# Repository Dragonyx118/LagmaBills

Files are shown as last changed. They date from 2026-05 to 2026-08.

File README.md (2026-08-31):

# L.A.G.M.A. B.I.L.L.S.
**L**and **A**nd **G**round-to-**M**idair **A**gent — **B**uilt for **I**ntelligent **L**inked **L**ocal **S**upport










A Mecanum-wheeled robot for civil protection, powered by a Raspberry Pi orchestrating two custom ESP32 PCBs, sensors, a robotic arm, and a drone companion over MQTT. It navigates autonomously, maps its environment, avoids obstacles, and is controlled via voice AI, a MAUI app, or browser dashboard.

Presentato ad Arduino Day 2025.

## Team
- **Daniele Cerioli (Dragonyx)** — firmware, software, PCB, integrazione di sistema
- **Simone Panelli (Tabella_Brodosa)** — componenti AI
- **Andrei Corduneanu** — modellazione 3D, falegnameria

## Repositories

| Repo | Contenuto |
|---|---|
| `lagmabills` (questo) | Firmware ESP32, codice Python Raspberry Pi, PCB (KiCad), modelli 3D |
| [`lagmabills-app`](https://github.com/Dragonyx118/LagmaIpp) | App companion LagmaIpp (.NET MAUI, Windows + Android) |
| [`lagmabills-web`](https://github.com/Dragonyx118/LagmaBills-Web) | Sito web del progetto |

## Struttura del repository

```
lagmabills/
├── firmware/
│   ├── firm_esp32_motori/     # Firmware PCBmotori (PlatformIO)
│   └── firm_esp32_sensori/    # Firmware PCBsensori (PlatformIO)
├── raspberry/
│   ├── odometria.py           # Odometria encoder Mecanum
│   ├── occupancyGrid.py       # Mappatura locale log-odds
│   ├── navigator.py           # Navigazione autonoma Potential Field
│   ├── GPS.py                 # Lettura NEO-6M → MQTT
│   ├── myViewerServer.py      # Dashboard web (HTTP + WebSocket + Leaflet)
│   ├── rasp_cam/              # Streaming camera OV5647
│   ├── odo_module/            # Moduli navigazione/mappatura aggiuntivi
│   └── Bamberg/
│       ├── ESP-IDF/           # Firmware ESP-Drone (ESP-IDF)
│       └── firm_drone/        # Bridge MQTT ↔ CRTP/UDP drone + test
├── AI_Bepo/                   # Server AI vocale (wakeword, STT, LLM, TTS)
├── AmazingArm/                # Modelli e risorse braccio robotico
├── PCB/
│   ├── PCBmotori/             # KiCad — ESP32 motori (4-layer)
│   ├── PCBsensori/            # KiCad — ESP32 sensori
│   └── PCBalim/               # KiCad — distribuzione alimentazione
├── Hardware/                  # Datasheet, pinout, power budget, BOM
├── models_3d/                 # Modelli 3D stampabili
└── docs/
    ├── img/                   # Foto e video dimostrativi
    └── LAGMABILLS.pptx        # Presentazione progetto
```

## Hardware

| Componente | Descrizione |
|---|---|
| Raspberry Pi 4B (4GB) | Cervello centrale, broker MQTT, Tailscale VPN |
| PCBmotori (ESP32, 4-layer) | 4× JGA25-370 Mecanum + encoder, 2× TB6612FNG, I2C slave 0x08 |
| PCBsensori (ESP32) | 6× HC-SR04, MPU-6050, 3× TCRT5000, PCA9685 → braccio 6DOF, I2C slave 0x09 |
| PCBalim | Distribuzione alimentazione custom, 2× LiPo 3S 5500mAh |
| ESP-Drone (ESP32-S2) | Ricognizione aerea, CRTP/UDP |
| OV5647 CSI | Camera RPi, stream MJPEG |
| ReSpeaker 2-Mic HAT | WM8960, wakeword ONNX, DOA GCC-PHAT |
| NEO-6M GPS | Tracciamento posizione world frame |
| Display 7" HDMI | Faccia animata responsiva (RPi) |
| Speaker Bluetooth | Audio stereo, musica / sirene / TTS |

Dettagli completi in [`Hardware/BOM.xlsx`](Hardware/BOM.xlsx) e [`Hardware/pinoutEsp32.xlsx`](Hardware/pinoutEsp32.xlsx).

## Architettura software

Tutto comunica via MQTT (Mosquitto su RPi, `localhost:1883`, accessibile anche via Tailscale).

```
              ┌─────────────────────────┐
              │  Mosquitto Broker (RPi) │
              └────────────┬────────────┘
     ┌──────────┬──────────┼──────────┬──────────┐
     │          │          │          │          │
odometria   occupancy   navigator  drone_bridge  GPS
     │        grid.py      .py        .py       .py
     │          │
  robot/     robot/
 motori/     mappa/
 stato       grid
```

| Topic | Direzione | Descrizione |
|---|---|---|
| `robot/motori/cmd` | Pi → ESP32 | Comandi movimento |
| `robot/motori/stato` | ESP32 → Pi | Encoder + PWM |
| `robot/sensori/distanze` | ESP32 → Pi | Distanze HC-SR04 (cm) |
| `robot/sensori/imu` | ESP32 → Pi | Accelerometro + giroscopio |
| `robot/odometria` | Pi → tutti | Posa X, Y, θ |
| `robot/mappa/grid` | Pi → viewer | Occupancy grid JSON |
| `robot/cliff/stato` | Pi → tutti | Stato sensori cliff |
| `robot/nav/cmd` | app → Pi | start / stop / reset_goal |
| `robot/nav/goal` | app → Pi | Goal `{x, y}` in world frame |
| `drone/cmd/rpyt` | app → Pi | Roll, pitch, yaw, thrust |

## Installazione (Raspberry Pi)

```bash
# Dipendenze Python
pip install paho-mqtt numpy sounddevice onnxruntime websockets \
            flask flask-socketio pyserial pynmea2 faster-whisper psutil

# Mosquitto broker
sudo apt install mosquitto mosquitto-clients
sudo systemctl enable mosquitto

# Driver ReSpeaker 2-Mic HAT
# Seguire istruzioni in Hardware/ o repo seeed-voicecard

# Avviare i moduli (esempio)
python3 raspberry/odometria.py &
python3 raspberry/occupancyGrid.py &
python3 raspberry/navigator.py &
python3 raspberry/GPS.py &
python3 raspberry/myViewerServer.py &
```

Dashboard web: `http://<ip-pi>:8080`

## Firmware ESP32 (PlatformIO)

Le cartelle in `firmware/` sono progetti PlatformIO completi e pronti da compilare (`pio run`).

Librerie richieste (`platformio.ini`):
- PubSubClient
- ArduinoJson
- MPU6050_light
- Adafruit PWM Servo Driver
- Preferences

Le credenziali WiFi e broker MQTT vengono salvate in NVS e possono essere aggiornate via I2C dal Pi senza reflashare.

📦 **Non vuoi compilare tu stesso?** Scarica le cartelle sorgente aggiornate automaticamente ad ogni modifica dalla sezione [Releases](../../releases).

## Pipeline AI vocale

```
ReSpeaker mic → wakeword ("hey nova") → DOA GCC-PHAT (stima direzione)
    → WebSocket stream PCM16 raw
    → Whisper STT → LLM (Ollama) → Piper TTS (voce "Miro" italiano)
    → audio risposta → Speaker Bluetooth
```

## Demo

**Primi test di movimento**

https://github.com/Dragonyx118/LagmaBills/raw/main/docs/img/first_test_move.mp4

**Prototipo in movimento**

https://github.com/Dragonyx118/LagmaBills/raw/main/docs/img/proto_move.mp4

**Test braccio robotico**

https://github.com/Dragonyx118/LagmaBills/raw/main/docs/img/test_arm.mp4

**Struttura in legno**

https://github.com/Dragonyx118/LagmaBills/raw/main/docs/img/wood_body.mp4

> GitHub riproduce automaticamente i link diretti `.mp4` di un repository quando incollati su una riga propria nel README, mostrando un player inline.

## Licenza

[Hippocratic License 3.0](LICENSE) (HL3-CL-ECO-LAW-MIL-SV) — © 2025 Dragonyx

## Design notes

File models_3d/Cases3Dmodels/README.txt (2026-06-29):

Raspberry Pi Cam Mount by ChisTompso on Thingiverse: https://www.thingiverse.com/thing:3445264

Summary:
I designed this thing for mounting my PiCam to my garage ceiling, but you could really use it for a variety of surfaces, hanging or standing.  Vertical vs. Horiztonal orientation of the PiCam video can be changed with a few quick settings.  It was specifically designed for the "Kuman for Raspberry PI Camera Module 5MP 1080p OV5647 Sensor HD Video Webcam Supports Night Vision SC15 (Raspberry PI Camera Module)", which can be found on Amazon and other places.Assembly of the mount requires a mixture of M3 screw/nut hardware.  You can find mixed assortments of M3 hardware easily on Amazon.  ABOUT THE MOUNTING BASE:Mounting Screws:  Two are required.  The base of the mount has a 3.5 mm radius counterbore for the screw heads, and a 2mm radius hole for the screws.  I just used some random dry wall screws that I had around the house.There are two mounting bases!  One lets the cable exit in the direction that the camera is looking (front cable exit). The other lets the cable exit in the opposite direction from where the camera is looking (rear cable exit).

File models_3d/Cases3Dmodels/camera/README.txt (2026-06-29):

Raspberry Pi3 IR Camera Wide-angle waterproof housing by bujna94 on Thingiverse: https://www.thingiverse.com/thing:3542321

Summary:
Hi, I designed this housing for: MakerHawk Raspberry Pi3 Camera IR Fisheye Wide-angle 175 Degree 5MP OV5647. Link to Amazon - https://amzn.to/2G10jXEI was printing it with PETG 100% infill, but PLA or ABS will be fine too. (PLA is not recommended for outdoor use). Gaskets I print with TPU 100% infill again. My printer is Ender 3 &amp; layer height was 0.3mm.The reason why the camera lens is not covered with plexiglass is night vision. If I just cover the whole camera with plexiglass, IR lights will reflect and you will be not able to see almost anything.I used 4 M3x16mm stainless steel pan head screws.It's not probably waterproof enough if you try to swim with it (didn't try), but more than enough for rain.You can also use some silicone to seal cable.Acrylic sheet is thick 3mm.Enjoy

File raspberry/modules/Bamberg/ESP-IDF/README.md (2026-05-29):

# L.A.G.M.A. B.I.L.L.S.
### *Land And Ground-to-Midair Agent — Built for Intelligent Linked Local Support*

> A Mecanum-wheeled robot for civil protection, powered by a Raspberry Pi orchestrating two custom ESP32 PCBs, sensors, a robotic arm, and a drone companion over MQTT. It navigates autonomously, maps its environment, avoids obstacles, and is controlled via voice AI, a MAUI app, or browser dashboard.

---

## Repositories

| Repo | Contenuto |
|---|---|
| **lagmabills** *(questo)* | Firmware ESP32, codice Python Raspberry Pi, PCB (KiCad) |
| **lagmabills-app** | App companion LagmaIpp (.NET MAUI, Windows + Android) |

---

## Struttura del repository

```
lagmabills/
├── firmware/
│   ├── esp32_motori/          # Firmware PCBmotori (PlatformIO)
│   └── esp32_sensori/         # Firmware PCBsensori (PlatformIO)
├── raspberry/
│   ├── wakeword.py            # Wakeword detection + DOA + WebSocket stream
│   ├── odometria.py           # Odometria encoder Mecanum
│   ├── occupancyGrid.py       # Mappatura locale log-odds
│   ├── navigator.py           # Navigazione autonoma Potential Field
│   ├── GPS.py                 # Lettura NEO-6M → MQTT
│   ├── drone_mqtt_bridge.py   # Bridge MQTT → CRTP/UDP drone
│   ├── myViewerServer.py      # Dashboard web (HTTP + WebSocket + Leaflet)
│   └── streamCamera.py        # Stream MJPEG OV5647
├── pcb/
│   ├── PCBmotori/             # KiCad — ESP32 motori (4-layer)
│   ├── PCBsensori/            # KiCad — ESP32 sensori
│   └── PCBalim/               # KiCad — distribuzione alimentazione
└── docs/
    └── LAGMABILLS.pptx        # Presentazione progetto
```

---

## Hardware

| Componente | Descrizione |
|---|---|
| Raspberry Pi 4B (4GB) | Cervello centrale, broker MQTT, Tailscale VPN |
| PCBmotori (ESP32, 4-layer) | 4× JGA25-370 Mecanum + encoder, 2× TB6612FNG, I2C slave `0x08` |
| PCBsensori (ESP32) | 6× HC-SR04, MPU-6050, 3× TCRT5000, PCA9685 → braccio 6DOF, I2C slave `0x09` |
| PCBalim | Distribuzione alimentazione custom, 2× LiPo 3S 5500mAh |
| ESP-Drone (ESP32-S2) | Ricognizione aerea, CRTP/UDP `192.168.43.42:2390` |
| OV5647 CSI | Camera RPi, stream MJPEG su porta `8080` |
| ReSpeaker 2-Mic HAT | WM8960, wakeword ONNX, DOA GCC-PHAT |
| NEO-6M GPS | Tracciamento posizione world frame |
| Display 7" HDMI | Faccia animata responsiva (RPi) |
| Speaker Bluetooth | Audio stereo, musica / sirene / TTS |

---

## Architettura software

Tutto comunica via **MQTT** (Mosquitto su RPi, `localhost:1883`, accessibile anche via Tailscale).

```
                    ┌─────────────────────────┐
                    │   Mosquitto Broker (RPi) │
                    └────────────┬────────────┘
           ┌──────────┬──────────┼──────────┬──────────┐
           │          │          │          │          │
      odometria   occupancy   navigator  drone_bridge  GPS
           │        grid.py      .py        .py       .py
           │          │
        robot/     robot/
       motori/     mappa/
       stato       grid
```

**Topic principali:**

| Topic | Direzione | Descrizione |
|---|---|---|
| `robot/motori/cmd` | Pi → ESP32 | Comandi movimento |
| `robot/motori/stato` | ESP32 → Pi | Encoder + PWM |
| `robot/sensori/distanze` | ESP32 → Pi | Distanze HC-SR04 (cm) |
| `robot/sensori/imu` | ESP32 → Pi | Accelerometro + giroscopio |
| `robot/odometria` | Pi → tutti | Posa X, Y, θ |
| `robot/mappa/grid` | Pi → viewer | Occupancy grid JSON |
| `robot/cliff/stato` | Pi → tutti | Stato sensori cliff |
| `robot/nav/cmd` | app → Pi | `start` / `stop` / `reset_goal` |
| `robot/nav/goal` | app → Pi | Goal `{x, y}` in world frame |
| `drone/cmd/rpyt` | app → Pi | Roll, pitch, yaw, thrust |
| `macchinina/audio/stop` | server → Pi | Stop streaming audio |

---

## Installazione (Raspberry Pi)

```bash
# Dipendenze Python
pip install paho-mqtt numpy sounddevice onnxruntime websockets \
            flask flask-socketio pyserial pynmea2 faster-whisper psutil

# Mosquitto broker
sudo apt install mosquitto mosquitto-clients
sudo systemctl enable mosquitto

# Driver ReSpeaker 2-Mic HAT
# Seguire istruzioni in docs/ o repo seeed-voicecard

# Avviare i moduli (esempio)
python3 raspberry/odometria.py &
python3 raspberry/occupancyGrid.py &
python3 raspberry/navigator.py &
python3 raspberry/GPS.py &
python3 raspberry/myViewerServer.py &
python3 raspberry/streamCamera.py &
```

**Dashboard web:** `http://<ip-pi>:8080`
**Stream camera:** `http://<ip-pi>:8080/stream`
**Accesso remoto:** `http://100.100.61.49:8080` (via Tailscale)

---

## Firmware ESP32 (PlatformIO)

Librerie richieste (`platformio.ini`):
```
PubSubClient
ArduinoJson
MPU6050_light
Adafruit PWM Servo Driver
Preferences
```

Le credenziali WiFi e broker MQTT vengono salvate in NVS e possono essere aggiornate via I2C dal Pi senza reflashare.

---

## Pipeline AI vocale

```
ReSpeaker mic → wakeword.py (hey_no_va.onnx)
    → DOA GCC-PHAT (stima direzione)
    → WebSocket stream PCM16 raw → ws://100.120.32.86:5000
    → Whisper STT → LLM → Piper TTS (voce "Miro" italiano)
    → audio risposta → Speaker Bluetooth
```

---

## Licenza

MIT License — © 2025 Daniele Cerioli

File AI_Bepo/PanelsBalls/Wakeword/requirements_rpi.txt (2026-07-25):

# requirements_rpi.txt - Solo per inferenza su Raspberry Pi
# Installa con: pip install -r requirements_rpi.txt
#
# NOTA: Su RPi 4/5 con Raspberry Pi OS Bookworm (64-bit)
#   sudo apt-get install -y portaudio19-dev libatlas-base-dev

# Inferenza (scegli UNO tra TFLite o ONNX)
tflite-runtime>=2.14.0       # OPZIONE A: più leggero (consigliato RPi)
# onnxruntime>=1.16.3        # OPZIONE B: onnx (migliore compatibilità)

# Audio streaming
pyaudio>=0.2.13
numpy>=1.24.0

# openWakeWord runtime (senza TF completo)
openwakeword>=0.6.0

# VAD leggero
webrtcvad>=2.0.10            # Google WebRTC VAD - <1ms latenza

# Utilities
pyyaml>=6.0.1

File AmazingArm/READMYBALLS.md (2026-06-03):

# 🤖 Robot Arm - Guida Completa

## Architettura del sistema

```
┌─────────────────────────────────────────────────────────┐
│  Smartphone / PC (Browser)                              │
│  └── Web Dashboard (index.html)                         │
└─────────────────────┬───────────────────────────────────┘
                      │ HTTP REST (WiFi)
┌─────────────────────▼───────────────────────────────────┐
│  Raspberry Pi                                           │
│  └── robot_arm_server.py (Flask, porta 5000)            │
└─────────────────────┬───────────────────────────────────┘
                      │ I2C (GPIO 2/3, bus 1)
┌─────────────────────▼───────────────────────────────────┐
│  ESP32                                                  │
│  ├── I2C slave (GPIO 16/17) ← RPi                       │
│  └── I2C master (GPIO 21/22) → PCA9685                  │
└─────────────────────┬───────────────────────────────────┘
                      │ PWM (16 canali)
┌─────────────────────▼───────────────────────────────────┐
│  PCA9685 Servo Driver                                   │
│  ├── CH0 → Servo 0: Base    (MG996R)                    │
│  ├── CH1 → Servo 1: Spalla  (MG996R)                    │
│  ├── CH2 → Servo 2: Gomito  (MG996R)                    │
│  ├── CH3 → Servo 3: Polso P (SG90)                      │
│  ├── CH4 → Servo 4: Polso R (SG90)                      │
│  └── CH5 → Servo 5: Gripper (SG90)                      │
└─────────────────────────────────────────────────────────┘
```

---

## Schema di collegamento

### ESP32 → PCA9685 (Bus I2C Master)
| ESP32 | PCA9685 |
|---|---|
| GPIO 21 (SDA) | SDA |
| GPIO 22 (SCL) | SCL |
| 3.3V | VCC |
| GND | GND |
| 5V ext  | V+ |  ← alimentazione servo (≥2A)

### Raspberry Pi → ESP32 (Bus I2C)
| RPi GPIO | ESP32 |
|---|---|
| GPIO 2 (SDA, pin 3) | GPIO 17 |
| GPIO 3 (SCL, pin 5) | GPIO 16 |
| GND (pin 6) | GND |

> ⚠️ **Importante:** RPi usa 3.3V su I2C, ESP32 è 3.3V compatibile → collegamento diretto OK.

### Alimentazione servo
```
Alimentatore 5V 3A ──► V+ PCA9685 (pin barilotto o morsetti)
                   └──► GND comune (ESP32, RPi, PCA9685)
```

---

## Installazione ESP32

### Librerie Arduino IDE necessarie
- `Adafruit PWM Servo Driver Library` (by Adafruit)
- `Wire` (inclusa)

### Passi
1. Apri Arduino IDE
2. Installa librerie via Library Manager
3. Seleziona board: **ESP32 Dev Module**
4. Carica `robot_arm_esp32.ino`

---

## Installazione Raspberry Pi

### Abilita I2C
```bash
sudo raspi-config
# → Interface Options → I2C → Enable
```

### Dipendenze Python
```bash
pip install flask flask-cors smbus2
```

### Avvio server
```bash
python3 robot_arm_server.py
```

### Avvio automatico al boot (systemd)
```bash
sudo nano /etc/systemd/system/robotarm.service
```
```ini
[Unit]
Description=Robot Arm Server
After=network.target

[Service]
ExecStart=/usr/bin/python3 /home/pi/robot_arm/robot_arm_server.py
WorkingDirectory=/home/pi/robot_arm
Restart=always
User=pi

[Install]
WantedBy=multi-user.target
```
```bash
sudo systemctl enable robotarm
sudo systemctl start robotarm
```

---

## Dashboard Web

Apri il browser e vai su:
```
http://<IP_RASPBERRY>:5000/
```

Oppure apri `index.html` localmente e imposta l'IP del RPi nella variabile `API` in cima allo script.

---

## API REST completa

| Metodo | Endpoint | Body | Descrizione |
|---|---|---|---|
| GET | `/status` | — | Stato corrente |
| POST | `/servo/<0-5>` | `{"angle": 90}` | Muovi servo singolo |
| POST | `/move_all` | `{"angles": [90,150,35,140,85,80]}` | Muovi tutti |
| POST | `/home` | — | Posizione HOME |
| POST | `/speed` | `{"speed": 50}` | Velocità (1-100) |
| POST | `/save_step` | — | Salva posizione corrente |
| POST | `/run_sequence` | — | Esegui sequenza |
| POST | `/reset_sequence` | — | Cancella sequenza |
| GET | `/sequence` | — | Lista step salvati |
| POST | `/preset/<nome>` | — | Esegui preset |
| GET | `/presets` | — | Lista preset disponibili |
| POST | `/pick` | `{"waist_angle": 90}` | Sequenza pick automatica |
| POST | `/place` | `{"waist_angle": 0}` | Sequenza place automatica |

### Preset disponibili
- `home` — posizione di riposo
- `pick_ready` — pronto per raccogliere
- `pick_open` — pinza aperta
- `pick_close` — pinza chiusa
- `place_ready` — pronto per depositare
- `place_drop` — rilascia oggetto
- `wave` — posizione laterale
- `rest` — braccio abbassato

### Esempio curl
```bash
# Muovi il servo base a 45°
curl -X POST http://192.168.1.10:5000/servo/0 -H "Content-Type: application/json" -d '{"angle":45}'

# Esegui sequenza pick
curl -X POST http://192.168.1.10:5000/pick -d '{"waist_angle": 90}'
```

---

## Protocollo I2C ESP32 (per sviluppatori)

| Byte 0 (cmd) | Payload | Azione |
|---|---|---|
| `0x01` | `[id, angolo]` | Muovi servo singolo |
| `0x02` | `[a0,a1,a2,a3,a4,a5]` | Muovi tutti |
| `0x03` | — | HOME |
| `0x04` | — | Richiedi stato (read) |
| `0x05` | `[velocità 1-100]` | Imposta velocità |
| `0x06` | — | Salva step corrente |
| `0x07` | — | Esegui sequenza |
| `0x08` | — | Reset sequenza |

---

## Troubleshooting

**I2C non trovato:**
```bash
i2cdetect -y 1   # deve mostrare 0x08 (ESP32)
```

**Servo tremano:**
- Verifica alimentazione (almeno 2A per MG996R)
- Aumenta `speedDelay` nell'ESP32

**Connessione dashboard fallisce:**
- Verifica IP RPi
- Controlla firewall: `sudo ufw allow 5000`

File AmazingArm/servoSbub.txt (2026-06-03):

ESP32          PCA9685
GPIO 21  →  SDA
GPIO 22  →  SCL
3.3V     →  VCC
GND      →  GND

Alimentazione servo (esterna):
6V dal tuo XL4015  →  V+  (terminale verde)
GND                →  GND (terminale verde)

--> controllare collegamento XL4015

CH0 → MG996R (vita)
CH1 → MG996R (spalla)
CH2 → MG996R (gomito)
CH3 → SG90   (polso roll)
CH4 → SG90   (polso pitch)
CH5 → SG90   (gripper)

--> godo già giusti credo

0x1A → ReSpeaker WM8960
0x08 → ESP32 motori/braccio
0x09 → ESP32 sensori (già definito)
0x40 → PCA9685 servo

--> raspeberry niente perchè master

---> controllare con oscillometro pca.setOscillatorFrequency(27000000);

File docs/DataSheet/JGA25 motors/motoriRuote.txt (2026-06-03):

Panoramica
Segnala l'articolo
Motoriduttore miniaturizzato DC 6V 12V 24V 12-1360 RPM con giunto Kit Smart Car ruota 65mm

Specifica:

Alta qualità e 100% nuovo di zecca

Volt nominale: 6v 12v 24v

Nessuna velocità di carico: 12/16/26/35/60/77/130/170/280/620/1360 RPM

Benvenuti nel nostro negozio, fornitura di fabbrica, fornire un servizio personalizzato per ordini oltre 100 pezzi.

Imballaggio incluso:

Kit ruota motoriduttore 1 x

Wirings:

Cavo rosso-alimentatore positivo del motore (+)(cambia positivo e negativo del motore la rotazione cambia)

Cavo bianco-alimentatore negativo del motore (-)(cambia positivo e negativo del motore la rotazione cambia))

Feedback del segnale a filo giallo (un giro del motore ha 11 segnali)

Green Wire-feedback del segnale (un giro del motore ha 11 segnali)

Blue Wire-positivo dell'alimentatore encoder (+)(3.3-5V), non può essere corretto

Filo nero-negativo dell'alimentatore encoder (-)(3.3-5V), non può essere corretto

Spettacolo di prodotti:

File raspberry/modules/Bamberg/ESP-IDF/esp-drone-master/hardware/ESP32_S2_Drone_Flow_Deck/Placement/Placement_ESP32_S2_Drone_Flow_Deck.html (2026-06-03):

D:\newFiles\e32336_esp32s2DroneShield\02_PCB\PCB_200616.pcb Create in 2020/6/16 20:44:25 Total components = 51 component(s)

Component Report
NO. | RefDes | PartDecal | Pins | Layer | Orient | PositionX | PositionY | IsSMD
1 | 1C1 | C0603 | 2 | Top | 180 | 13.100 | 38.379 | Yes
2 | 1C2 | C0402 | 2 | Top | 180 | 13.350 | 37.129 | Yes
3 | 1C3 | C0603 | 2 | Top | 180 | 13.050 | 35.879 | Yes
4 | 1C4 | C0402 | 2 | Top | 180 | 13.350 | 34.679 | Yes
5 | 1C5 | C0603 | 2 | Top | 180 | 13.100 | 32.629 | Yes
6 | 1C6 | C0402 | 2 | Top | 180 | 13.350 | 33.779 | Yes
7 | 1C7 | C0603 | 2 | Top | 0 | 13.100 | 45.879 | Yes
8 | 1C8 | C0603 | 2 | Top | 0 | 13.100 | 39.879 | Yes
9 | 1C9 | C0603 | 2 | Top | 0 | 18.300 | 46.979 | Yes
10 | 1C10 | C0402 | 2 | Top | 270 | 20.800 | 43.479 | Yes
11 | 1C11 | C0402 | 2 | Top | 0 | 18.050 | 45.729 | Yes
12 | 1J1 | CON8-S-2P0 | 16 | Bottom | 90 | 27.800 | 39.629 | No
13 | 1J2 | CON8-S-2P0 | 16 | Bottom | 90 | 2.800 | 39.629 | No
14 | 1R1 | R0402 | 2 | Top | 0 | 13.355 | 31.208 | Yes
15 | 1R2 | R0402 | 2 | Top | 180 | 7.300 | 32.629 | Yes
16 | 1R3 | R0402 | 2 | Top | 180 | 7.300 | 36.629 | Yes
17 | 1R4 | R0402 | 2 | Top | 180 | 7.300 | 38.629 | Yes
18 | 1R5 | R0402 | 2 | Top | 90 | 20.800 | 41.279 | Yes
19 | 1U1 | COB28_0P65_6X6 | 29 | Top | 0 | 18.300 | 34.629 | Yes
20 | 1U2 | SOT-23-5 | 5 | Top | 270 | 12.850 | 42.879 | Yes
21 | 1U3 | LGA12_0P8_2P5X4P9 | 12 | Top | 0 | 18.300 | 42.479 | Yes
22 | 2C1 | C0402 | 2 | Top | 180 | 8.050 | 12.016 | Yes
23 | 2C2 | C0402 | 2 | Top | 180 | 8.050 | 11.016 | Yes
24 | 2C3 | C0402 | 2 | Top | 90 | 11.800 | 14.766 | Yes
25 | 2C4 | C0402 | 2 | Top | 270 | 14.400 | 11.200 | Yes
26 | 2C5 | C0402 | 2 | Top | 270 | 13.400 | 11.200 | Yes
27 | 2C6 | C0402 | 2 | Top | 270 | 16.800 | 11.766 | Yes
28 | 2J1 | CON8-S-2P0 | 16 | Top | 90 | 2.800 | 11.766 | No
29 | 2J2 | CON8-S-2P0 | 16 | Top | 90 | 27.800 | 11.766 | No
30 | 2U1 | LPCC16_0P5_3X3 | 16 | Top | 0 | 11.050 | 11.766 | Yes
31 | 2U2 | QFN8_1P25_3X5 | 8 | Top | 0 | 19.550 | 11.766 | Yes
32 | T1 | HOLE_0P6 | 1 | Top | 0 | 7.000 | 27.864 | No
33 | T2 | HOLE_0P6 | 1 | Top | 0 | 7.900 | 27.864 | No
34 | T3 | HOLE_0P6 | 1 | Top | 0 | 8.800 | 27.864 | No
35 | T4 | HOLE_0P6 | 1 | Top | 0 | 9.700 | 27.864 | No
36 | T5 | HOLE_0P6 | 1 | Top | 0 | 10.600 | 27.864 | No
37 | T6 | HOLE_0P6 | 1 | Top | 0 | 10.600 | 23.500 | No
38 | T7 | HOLE_0P6 | 1 | Top | 0 | 9.700 | 23.500 | No
39 | T8 | HOLE_0P6 | 1 | Top | 0 | 8.800 | 23.500 | No
40 | T9 | HOLE_0P6 | 1 | Top | 0 | 7.900 | 23.500 | No
41 | T10 | HOLE_0P6 | 1 | Top | 0 | 7.000 | 23.500 | No
42 | T11 | HOLE_0P6 | 1 | Top | 0 | 19.600 | 27.864 | No
43 | T12 | HOLE_0P6 | 1 | Top | 0 | 20.500 | 27.864 | No
44 | T13 | HOLE_0P6 | 1 | Top | 0 | 21.400 | 27.864 | No
45 | T14 | HOLE_0P6 | 1 | Top | 0 | 22.300 | 27.864 | No
46 | T15 | HOLE_0P6 | 1 | Top | 0 | 23.200 | 27.864 | No
47 | T16 | HOLE_0P6 | 1 | Top | 0 | 19.600 | 23.500 | No
48 | T17 | HOLE_0P6 | 1 | Top | 0 | 20.500 | 23.500 | No
49 | T18 | HOLE_0P6 | 1 | Top | 0 | 21.400 | 23.500 | No
50 | T19 | HOLE_0P6 | 1 | Top | 0 | 22.300 | 23.500 | No
51 | T20 | HOLE_0P6 | 1 | Top | 0 | 23.200 | 23.500 | No

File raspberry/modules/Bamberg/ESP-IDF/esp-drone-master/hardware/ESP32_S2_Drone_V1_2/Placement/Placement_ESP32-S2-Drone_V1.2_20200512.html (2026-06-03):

D:\WORK\#31436_ESP32-S2-ESPlane-KIT_M_V1.0_N_XX_20200325_V0.1\#31436_ESP32-S2-ESPlane-KIT_M_V1.2_N_XX_20200511_V0.3\02_PCB/PCB_ESP32-S2-Drone_V1.2_20200512.pcb Create in 2020/5/12 17:13:59 Total components = 203 component(s)

Component Report
NO. | RefDes | PartDecal | Pins | Layer | Orient | PositionX | PositionY | IsSMD
1 | C1 | C0603 | 2 | Top | 180 | 1571.554 | 2462.404 | Yes
2 | C2 | C0402 | 2 | Top | 90 | 1685.304 | 2562.104 | Yes
3 | C3 | C0603 | 2 | Top | 180 | 1555.454 | 2230.404 | Yes
4 | C4 | C0402 | 2 | Top | 270 | 1923.504 | 2559.904 | Yes
5 | C5 | C0402 | 2 | Top | 270 | 1771.004 | 2562.104 | Yes
6 | C6 | C0603 | 2 | Top | 0 | 2787.933 | 2016.722 | Yes
7 | C7 | C0402 | 2 | Top | 0 | 2808.406 | 1922.234 | Yes
8 | C8 | C0603 | 2 | Top | 180 | 2671.004 | 2016.722 | Yes
9 | C9 | C0402 | 2 | Top | 90 | 2750.925 | 1943.888 | Yes
10 | C10 | C0603 | 2 | Top | 180 | 1711.454 | 2230.404 | Yes
11 | C11 | C0603 | 2 | Top | 180 | 1706.504 | 2462.404 | Yes
12 | C12 | C0603 | 2 | Top | 180 | 1426.004 | 2117.254 | Yes
13 | C13 | C0402 | 2 | Top | 0 | 2231.004 | 2304.754 | Yes
14 | C14 | C0603 | 2 | Top | 90 | 2369.754 | 2361.004 | Yes
15 | C15 | C0603 | 2 | Top | 90 | 2169.754 | 2403.504 | Yes
16 | C16 | C0603 | 2 | Top | 180 | 2409.843 | 1237.402 | Yes
17 | C17 | C0402 | 2 | Top | 180 | 2398.031 | 1188.189 | Yes
18 | C18 | C0402 | 2 | Top | 270 | 1571.260 | 1214.173 | Yes
19 | C19 | C0402 | 2 | Top | 270 | 1852.254 | 2286.004 | Yes
20 | C20 | C0402 | 2 | Top | 0 | 2028.839 | 2377.254 | Yes
21 | C21 | C0402 | 2 | Top | 90 | 1959.604 | 2393.504 | Yes
22 | C22 | C0402 | 2 | Top | 180 | 1918.504 | 2141.004 | Yes
23 | C23 | C0402 | 2 | Top | 0 | 1139.370 | 1915.354 | Yes
24 | C24 | C0402 | 2 | Top | 0 | 1139.754 | 1604.754 | Yes
25 | D1 | SOD523 | 2 | Top | 315 | 1382.254 | 1399.754 | Yes
26 | D2 | SOD523 | 2 | Top | 45 | 1389.754 | 2547.254 | Yes
27 | D3 | SOD323 | 2 | Top | 90 | 2376.004 | 2237.254 | Yes
28 | D4 | SOD523 | 2 | Top | 135 | 2549.754 | 2552.254 | Yes
29 | D5 | SOD523 | 2 | Top | 0 | 2744.754 | 1419.754 | Yes
30 | D6 | LED3010-S | 3 | Top | 0 | 1476.378 | 2814.961 | Yes
31 | D7 | LED3010-S | 3 | Top | 180 | 1476.378 | 1122.047 | Yes
32 | D8 | LED3010-S | 3 | Top | 0 | 2460.630 | 2814.961 | Yes
33 | D9 | LED3010-S | 3 | Top | 180 | 2460.630 | 1122.047 | Yes
34 | FB1 | L0603 | 2 | Top | 90 | 2409.754 | 1328.504 | Yes
35 | H1 | P_2X1 | 1 | Bottom | 135 | 2814.964 | 2657.484 | Yes
36 | H58 | P_2X1 | 1 | Bottom | 45 | 708.661 | 3346.457 | Yes
37 | H59 | P_2X1 | 1 | Bottom | 45 | 1279.528 | 2814.961 | Yes
38 | H60 | P_2X1 | 1 | Bottom | 45 | 2657.480 | 1122.047 | Yes
39 | H61 | P_2X1 | 1 | Bottom | 45 | 3228.346 | 590.551 | Yes
40 | H62 | P_2X1 | 1 | Bottom | 135 | 1122.047 | 1279.528 | Yes
41 | H63 | P_2X1 | 1 | Bottom | 45 | 1122.047 | 2657.480 | Yes
42 | H65 | P_2X1 | 1 | Bottom | 45 | 3346.457 | 708.661 | Yes
43 | H66 | P_2X1 | 1 | Bottom | 135 | 2657.480 | 2814.961 | Yes
44 | H67 | P_2X1 | 1 | Bottom | 135 | 1279.528 | 1122.047 | Yes
45 | H68 | P_2X1 | 1 | Bottom | 135 | 590.551 | 708.661 | Yes
46 | H69 | P_2X1 | 1 | Bottom | 45 | 590.551 | 3228.346 | Yes
47 | H70 | P_2X1 | 1 | Bottom | 45 | 2814.961 | 1279.528 | Yes
48 | H71 | P_2X1 | 1 | Bottom | 135 | 3346.457 | 3228.346 | Yes
49 | H72 | P_2X1 | 1 | Bottom | 135 | 708.661 | 590.551 | Yes
50 | H73 | P_2X1 | 1 | Bottom | 135 | 3228.346 | 3346.457 | Yes
51 | J1 | USB_5P_MICRO_F | 11 | Top | 180 | 2638.504 | 2303.504 | No
52 | J2 | FFC24-0P5 | 26 | Top | 180 | 1968.504 | 2736.220 | Yes
53 | J3 | A2005HWV-S-XP-A | 16 | Top | 270 | 2460.630 | 1751.969 | No
54 | J4 | A2005HWV-S-XP-A | 16 | Top | 270 | 1476.378 | 1751.969 | No
55 | J5 | CON2X1_1P5_SMT_ZH-2A_DIP | 4 | Top | 45 | 2678.504 | 2678.504 | No
56 | J6 | CON2X1_1P5_SMT_ZH-2A_DIP | 4 | Top | 315 | 2678.504 | 1258.504 | No
57 | J7 | CON2X1_2P0_SMT_PH2A-S-A | 4 | Top | 270 | 1478.346 | 2288.504 | Yes
58 | J8 | CON2X1_1P5_SMT_ZH-2A_DIP | 4 | Top | 225 | 1258.504 | 1258.504 | No
59 | J9 | CON2X1_1P5_SMT_ZH-2A_DIP | 4 | Top | 135 | 1258.504 | 2678.504 | No
60 | J10 | A2005HWV-S-XP-A | 16 | Top | 270 | 1476.378 | 463.219 | No
61 | J11 | A2005HWV-S-XP-A | 16 | Top | 270 | 2460.630 | 463.219 | No
62 | Q3 | SOT-23-3 | 3 | Top | 180 | 1291.334 | 2033.504 | Yes
63 | Q4 | SOT-23-3 | 3 | Top | 0 | 1218.504 | 1512.004 | Yes
64 | Q5 | SOT-23-3 | 3 | Top | 270 | 1518.504 | 2667.254 | Yes
65 | Q6 | SOT-23-3 | 3 | Top | 90 | 2418.504 | 2667.504 | Yes
66 | Q7 | SOT-23-3 | 3 | Top | 0 | 2718.504 | 1512.004 | Yes
67 | R1 | R0402 | 2 | Top | 180 | 2533.504 | 2143.504 | Yes
68 | R3 | R0402 | 2 | Top | 0 | 2454.754 | 2143.504 | Yes
69 | R5 | R0402 | 2 | Top | 90 | 1868.404 | 2559.904 | Yes
70 | R6 | R0402 | 2 | Top | 270 | 1736.904 | 2562.104 | Yes
71 | R7 | R0402 | 2 | Top | 90 | 2709.193 | 1943.888 | Yes
72 | R8 | R0402 | 2 | Top | 0 | 2808.012 | 1963.967 | Yes
73 | R9 | R0402 | 2 | Top | 0 | 2646.201 | 1929.321 | Yes
74 | R10 | R0402 | 2 | Top | 0 | 2646.201 | 1964.754 | Yes
75 | R11 | R0402 | 2 | Top | 90 | 1321.260 | 1581.890 | Yes
76 | R12 | R0402 | 2 | Top | 90 | 1356.693 | 1581.890 | Yes
77 | R13 | R0402 | 2 | Top | 180 | 1232.254 | 1604.754 | Yes
78 | R14 | R0402 | 2 | Top | 180 | 1675.504 | 2619.904 | Yes
79 | R15 | R0402 | 2 | Top | 90 | 2583.996 | 1996.348 | Yes
80 | R16 | R0402 | 2 | Top | 270 | 2583.996 | 1916.148 | Yes
81 | R17 | R0402 | 2 | Top | 0 | 1253.504 | 2123.504 | Yes
82 | R18 | R0402 | 2 | Top | 180 | 2231.004 | 2267.854 | Yes
83 | R19 | R0402 | 2 | Top | 0 | 1139.754 | 1871.004 | Yes
84 | R20 | R0402 | 2 | Top | 90 | 2287.254 | 2288.504 | Yes
85 | R21 | R0402 | 2 | Top | 180 | 1538.976 | 1357.480 | Yes
86 | R22 | R0402 | 2 | Top | 90 | 1536.614 | 1214.173 | Yes
87 | R23 | R0402 | 2 | Top | 180 | 2381.004 | 2563.504 | Yes
88 | R24 | R0402 | 2 | Top | 90 | 2622.254 | 1529.754 | Yes
89 | R25 | R0402 | 2 | Top | 180 | 1538.976 | 1397.638 | Yes
90 | R26 | R0402 | 2 | Top | 180 | 1516.004 | 2763.504 | Yes
91 | R27 | R0402 | 2 | Top | 0 | 2018.604 | 2121.004 | Yes
92 | R28 | R0402 | 2 | Top | 0 | 1887.254 | 2377.254 | Yes
93 | R29 | R0402 | 2 | Top | 90 | 1448.504 | 1214.754 | Yes
94 | R30 | R0402 | 2 | Top | 180 | 2499.754 | 2763.504 | Yes
95 | R31 | R0402 | 2 | Top | 0 | 2476.772 | 1188.189 | Yes
96 | R32 | R0402 | 2 | Top | 270 | 2086.004 | 2360.504 | Yes
97 | R33 | R0402 | 2 | Top | 90 | 2086.004 | 2280.504 | Yes
98 | R34 | R0402 | 2 | Top | 0 | 1282.254 | 1759.754 | Yes
99 | R35 | R0402 | 2 | Top | 90 | 1344.754 | 1702.254 | Yes
100 | SW1 | SW4_3X3P5X1P1_SMT | 6 | Top | 270 | 1141.704 | 2047.244 | No
101 | SW2 | SW4_3X3P5X1P1_SMT | 6 | Top | 270 | 1141.732 | 1740.157 | No
102 | T1 | K_3X2 | 1 | Top | 0 | 68.504 | 2242.504 | No
103 | T2 | K_3X2 | 1 | Top | 0 | 68.504 | 2095.504 | No
104 | T3 | K_3X2 | 1 | Top | 0 | 720.472 | 2242.504 | No
105 | T4 | K_3X2 | 1 | Top | 0 | 720.472 | 2095.504 | No
106 | T5 | K_3X2 | 1 | Top | 0 | 68.504 | 1841.504 | No
107 | T6 | K_3X2 | 1 | Top | 0 | 68.504 | 1694.504 | No
108 | T7 | K_3X2 | 1 | Top | 0 | 720.474 | 1841.504 | No
109 | T8 | K_3X2 | 1 | Top | 0 | 720.472 | 1694.504 | No
110 | T9 | K_3X2 | 1 | Top | 180 | 1648.504 | 3512.254 | No
111 | T10 | K_3X2 | 1 | Top | 180 | 1648.504 | 3366.004 | No
112 | T11 | K_3X2 | 1 | Top | 180 | 3868.504 | 2242.504 | No
113 | T12 | K_3X2 | 1 | Top | 180 | 3868.504 | 2094.754 | No
114 | T13 | K_3X2 | 1 | Top | 180 | 2276.504 | 3512.254 | No
115 | T14 | K_3X2 | 1 | Top | 180 | 2276.504 | 3366.004 | No
116 | T15 | K_3X2 | 1 | Top | 180 | 3868.504 | 1841.504 | No
117 | T16 | K_3X2 | 1 | Top | 180 | 3868.504 | 1694.754 | No
118 | T17 | K_3X2 | 1 | Top | 0 | 3216.504 | 2242.504 | No
119 | T18 | K_3X2 | 1 | Top | 0 | 3216.504 | 2095.504 | No
120 | T19 | K_3X2 | 1 | Top | 0 | 3216.504 | 1841.504 | No
121 | T20 | K_3X2 | 1 | Top | 0 | 3216.504 | 1694.504 | No
122 | T21 | SMD_3X6 | 1 | Top | 225 | 3359.055 | 495.669 | No
123 | T22 | HOLE_0P6 | 1 | Top | 0 | 717.649 | 2527.559 | No
124 | T23 | SMD_3X6 | 1 | Top | 45 | 3881.102 | 136.220 | No
125 | T24 | SMD_3X6 | 1 | Top | 135 | 3813.386 | 3888.583 | No
126 | T25 | SMD_3X6 | 1 | Top | 315 | 3446.063 | 3375.591 | No
127 | T26 | SMD_3X6 | 1 | Top | 225 | 47.638 | 3812.205 | No
128 | T27 | SMD_3X6 | 1 | Top | 45 | 585.039 | 3433.071 | No
129 | T28 | SMD_3X6 | 1 | Top | 135 | 497.638 | 582.677 | No
130 | T29 | SMD_3X6 | 1 | Top | 315 | 124.409 | 45.669 | No
131 | T30 | HOLE_0P6 | 1 | Top | 0 | 717.649 | 2500.000 | No
132 | T31 | HOLE_0P6 | 1 | Top | 0 | 717.649 | 2472.441 | No
133 | T32 | HOLE_0P6 | 1 | Top | 0 | 717.649 | 2417.323 | No
134 | T33 | HOLE_0P6 | 1 | Top | 0 | 717.649 | 1519.685 | No
135 | T34 | HOLE_0P6 | 1 | Top | 0 | 717.649 | 1492.126 | No
136 | T35 | HOLE_0P6 | 1 | Top | 0 | 717.649 | 1464.567 | No
137 | T36 | HOLE_0P6 | 1 | Top | 0 | 717.649 | 1409.449 | No
138 | T37 | HOLE_0P6 | 1 | Top | 0 | 717.649 | 1437.008 | No
139 | T38 | HOLE_0P6 | 1 | Top | 0 | 1076.772 | 1519.685 | No
140 | T39 | HOLE_0P6 | 1 | Top | 0 | 1076.772 | 1492.126 | No
141 | T40 | HOLE_0P6 | 1 | Top | 0 | 1076.772 | 1464.567 | No
142 | T41 | HOLE_0P6 | 1 | Top | 0 | 1076.772 | 1409.449 | No
143 | T42 | HOLE_0P6 | 1 | Top | 0 | 1076.772 | 1437.008 | No
144 | T43 | HOLE_0P6 | 1 | Top | 0 | 1076.772 | 2531.496 | No
145 | T44 | HOLE_0P6 | 1 | Top | 0 | 1076.772 | 2503.937 | No
146 | T45 | HOLE_0P6 | 1 | Top | 0 | 1076.772 | 2476.378 | No
147 | T46 | HOLE_0P6 | 1 | Top | 0 | 1076.772 | 2448.819 | No
148 | T47 | HOLE_0P6 | 1 | Top | 0 | 1076.772 | 2421.260 | No
149 | T48 | HOLE_0P6 | 1 | Top | 0 | 3219.359 | 2531.496 | No
150 | T49 | HOLE_0P6 | 1 | Top | 0 | 3219.359 | 2503.937 | No
151 | T50 | HOLE_0P6 | 1 | Top | 0 | 3219.359 | 2476.378 | No
152 | T51 | HOLE_0P6 | 1 | Top | 0 | 3219.359 | 2448.819 | No
153 | T52 | HOLE_0P6 | 1 | Top | 0 | 3219.359 | 2421.260 | No
154 | T53 | HOLE_0P6 | 1 | Top | 0 | 3219.359 | 1515.748 | No
155 | T54 | HOLE_0P6 | 1 | Top | 0 | 3219.359 | 1488.189 | No
156 | T55 | HOLE_0P6 | 1 | Top | 0 | 3219.359 | 1460.630 | No
157 | T56 | HOLE_0P6 | 1 | Top | 0 | 3219.359 | 1433.071 | No
158 | T57 | HOLE_0P6 | 1 | Top | 0 | 3219.359 | 1405.512 | No
159 | T58 | HOLE_0P6 | 1 | Top | 0 | 717.649 | 2444.882 | No
160 | T59 | HOLE_0P6 | 1 | Top | 0 | 2860.236 | 1519.685 | No
161 | T60 | HOLE_0P6 | 1 | Top | 0 | 2860.236 | 1492.126 | No
162 | T61 | HOLE_0P6 | 1 | Top | 0 | 2860.236 | 1464.567 | No
163 | T62 | HOLE_0P6 | 1 | Top | 0 | 2860.236 | 1437.008 | No
164 | T63 | HOLE_0P6 | 1 | Top | 0 | 2860.236 | 1409.449 | No
165 | T64 | HOLE_0P6 | 1 | Top | 0 | 2860.236 | 2531.496 | No
166 | T65 | HOLE_0P6 | 1 | Top | 0 | 2860.236 | 2503.937 | No
167 | T66 | HOLE_0P6 | 1 | Top | 0 | 2860.236 | 2476.378 | No
168 | T67 | HOLE_0P6 | 1 | Top | 0 | 2860.236 | 2448.819 | No
169 | T68 | HOLE_0P6 | 1 | Top | 0 | 2860.236 | 2421.260 | No
170 | T69 | HOLE_0P6 | 1 | Top | 0 | 1549.291 | 1074.803 | No
171 | T70 | HOLE_0P6 | 1 | Top | 0 | 1576.850 | 1074.803 | No
172 | T71 | HOLE_0P6 | 1 | Top | 0 | 1604.409 | 1074.803 | No
173 | T72 | HOLE_0P6 | 1 | Top | 0 | 1631.969 | 1074.803 | No
174 | T73 | HOLE_0P6 | 1 | Top | 0 | 1549.291 | 925.197 | No
175 | T74 | HOLE_0P6 | 1 | Top | 0 | 1576.850 | 925.197 | No
176 | T75 | HOLE_0P6 | 1 | Top | 0 | 1604.409 | 925.197 | No
177 | T76 | HOLE_0P6 | 1 | Top | 0 | 1631.969 | 925.197 | No
178 | T77 | HOLE_0P6 | 1 | Top | 0 | 2305.315 | 925.197 | No
179 | T78 | HOLE_0P6 | 1 | Top | 0 | 2332.874 | 925.197 | No
180 | T79 | HOLE_0P6 | 1 | Top | 0 | 2360.433 | 925.197 | No
181 | T80 | HOLE_0P6 | 1 | Top | 0 | 2387.992 | 925.197 | No
182 | T81 | HOLE_0P6 | 1 | Top | 0 | 2305.315 | 1074.803 | No
183 | T82 | HOLE_0P6 | 1 | Top | 0 | 2332.874 | 1074.803 | No
184 | T83 | HOLE_0P6 | 1 | Top | 0 | 2360.433 | 1074.803 | No
185 | T84 | HOLE_0P6 | 1 | Top | 0 | 2387.992 | 1074.803 | No
186 | T85 | HOLE_0P6 | 1 | Top | 0 | 1913.386 | 3464.567 | No
187 | T86 | HOLE_0P6 | 1 | Top | 0 | 1940.945 | 3464.567 | No
188 | T87 | HOLE_0P6 | 1 | Top | 0 | 1968.504 | 3464.567 | No
189 | T88 | HOLE_0P6 | 1 | Top | 0 | 1996.063 | 3464.567 | No
190 | T89 | HOLE_0P6 | 1 | Top | 0 | 2023.622 | 3464.567 | No
191 | T91 | HOLE_0P6 | 1 | Top | 0 | 1913.386 | 2862.205 | No
192 | T92 | HOLE_0P6 | 1 | Top | 0 | 1940.945 | 2862.205 | No
193 | T93 | HOLE_0P6 | 1 | Top | 0 | 1968.504 | 2862.205 | No
194 | T94 | HOLE_0P6 | 1 | Top | 0 | 1996.063 | 2862.205 | No
195 | T95 | HOLE_0P6 | 1 | Top | 0 | 2023.622 | 2862.205 | No
196 | U1 | SOT23-6 | 6 | Top | 270 | 2493.504 | 2253.504 | Yes
197 | U2 | SOT-23-5 | 5 | Top | 90 | 1500.354 | 2313.104 | Yes
198 | U3 | QFN28_0P5_5 | 29 | Top | 180 | 2688.720 | 1776.959 | Yes
199 | U4 | SOT-23-5 | 5 | Top | 90 | 1656.354 | 2313.104 | Yes
200 | U5 | DFN3030-8 | 9 | Top | 270 | 2264.754 | 2392.254 | Yes
201 | U6 | ESP32-S2-WROVER | 43 | Top | 180 | 2322.835 | 834.646 | Yes
202 | U7 | QFN24_0P5_4_A | 24 | Top | 180 | 1968.504 | 2256.204 | Yes
203 | U8 | SOT363 | 6 | Top | 90 | 1284.754 | 1689.754 | Yes

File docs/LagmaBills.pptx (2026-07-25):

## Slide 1

Sigma & co

About

Project

Service

Team

Log In

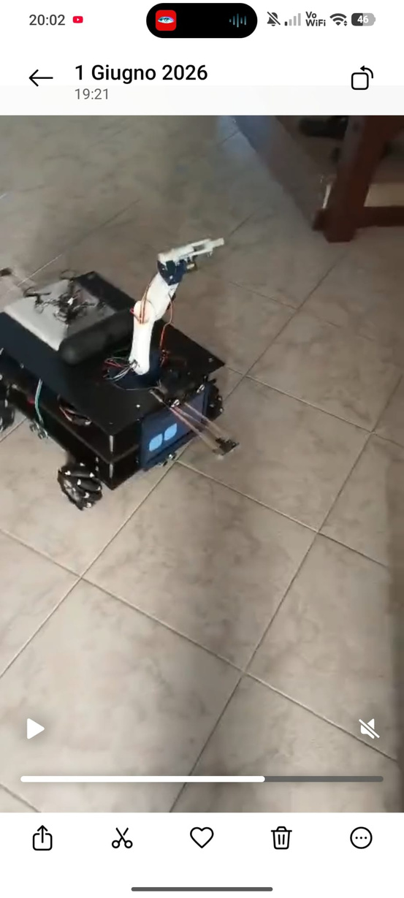
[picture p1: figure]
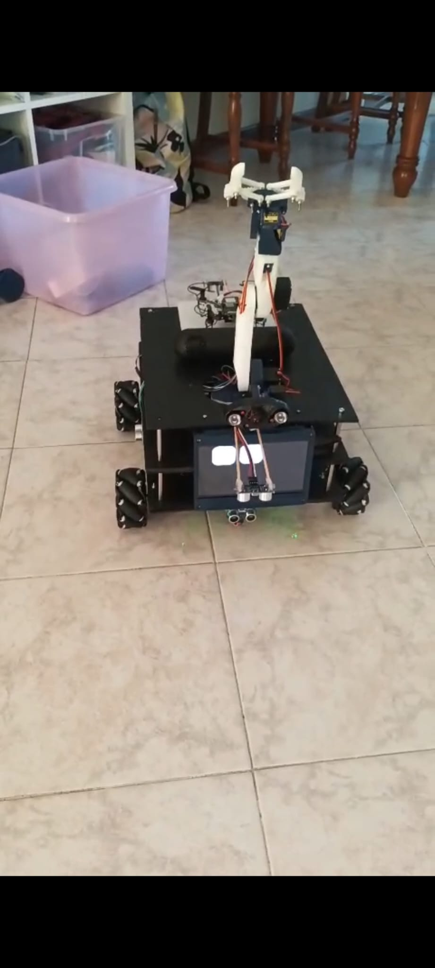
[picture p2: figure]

95k+

cavi

100k+

idee

LagmaBills

Daniele Cerioli, Simone Panelli, Andrei Corduneanu

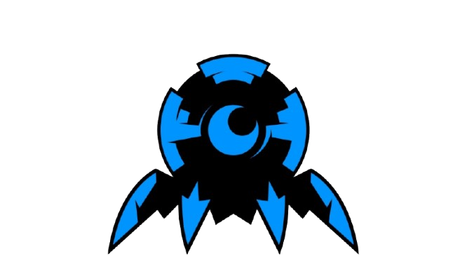
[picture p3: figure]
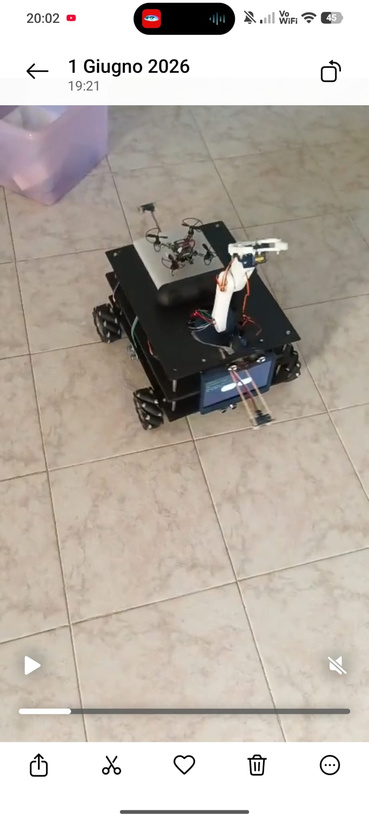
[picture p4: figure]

Galileo Galilei Crema 4IC

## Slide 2

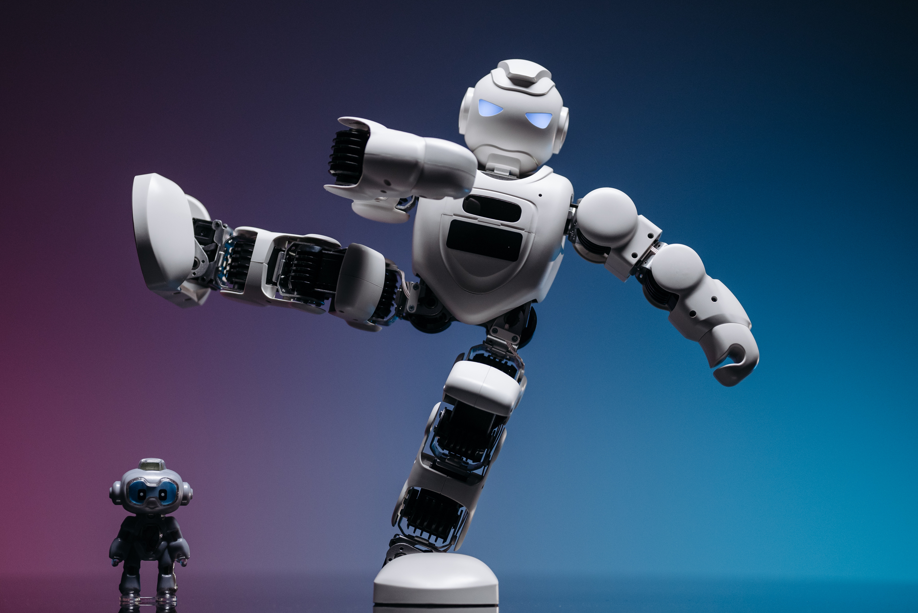
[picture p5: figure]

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
uilt for

ntelligent

nd

round

idair

gent

inked

ocal

upport

The Meaning of LagmaBills

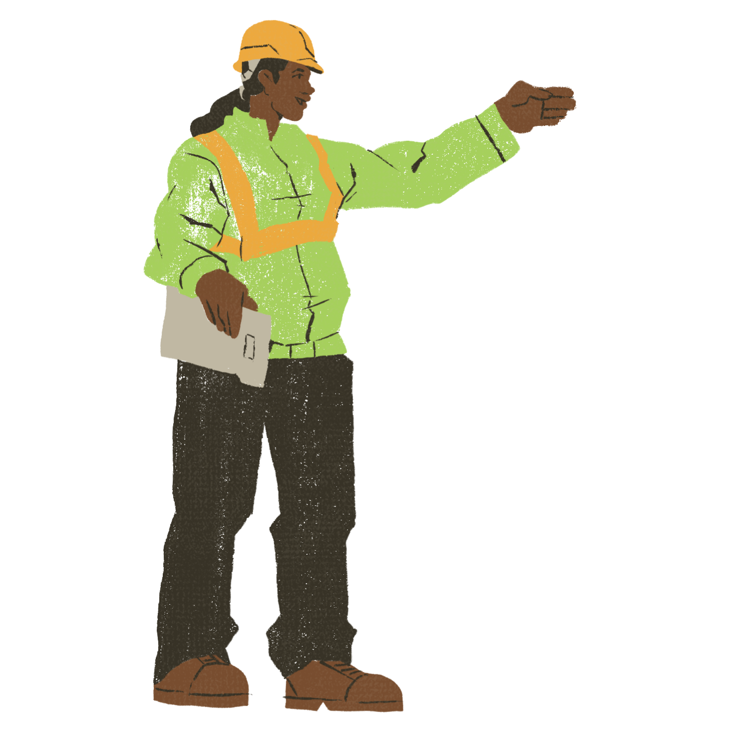
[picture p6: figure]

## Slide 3

Sigma & CO.

Search...

About

Project

Service

Team

Log In

The purpose of LagmaBills

LagmaBills è una macchina con braccio robotico e drone di pattuglia di supporto per situazioni di emergenza/pericolo; ha un assistente vocale (AI locale su server), e sistema di mappatura con odometria intelligente tramite i sensori a ultrasuoni per poter muoversi autonomamente senza schiantarsi. Il tutto è formato da 2 esp32 e 1 raspberry che comunicano tra loro e con l’app Android (con cui la si può controllare e monitorare da qualsiasi distanza) tramite un sistema di una VPN con una LAN privata per i dispositivi che fanno parte del sistema tramite MQTT (mosquitto sul raspberry).

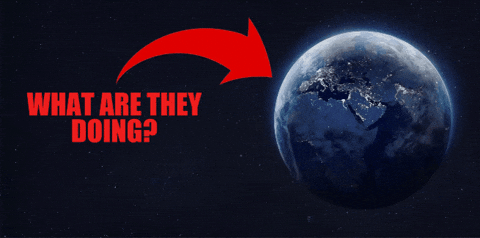
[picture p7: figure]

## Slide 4

Sigma & CO.

Search...

About

Project

Service

Team

Log In

What Is LagmaBills Made Of

LagmaBills principalmente è composta da tre tavolette di legno spesse 0.5 cm poste una sopra l’altra, che danno una base solida all’intera struttura. Inoltre le tavolette sono rette da dei pilastri in acciaio presi da bulloni, offrendo a LagmaBills leggerezza, facilità di lavorazione e resistenza, rendendo il sistema allo stesso tempo robusto e modulare

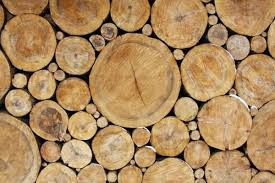
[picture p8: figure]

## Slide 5

Sigma & CO.

Search...

About

Project

Service

Team

Log In

The Heart Of LagmaBills

Il cuore di LagmaBIlls è un raspberry che fa da centro di comunicazione di tutto il sistema, facendo da broker mqtt (mosquitto) ad un indirizzo fisso via VPN Tailscale con mDNS per farla rilevare dagli esp32 anchessi collegati nella stessa rete internet

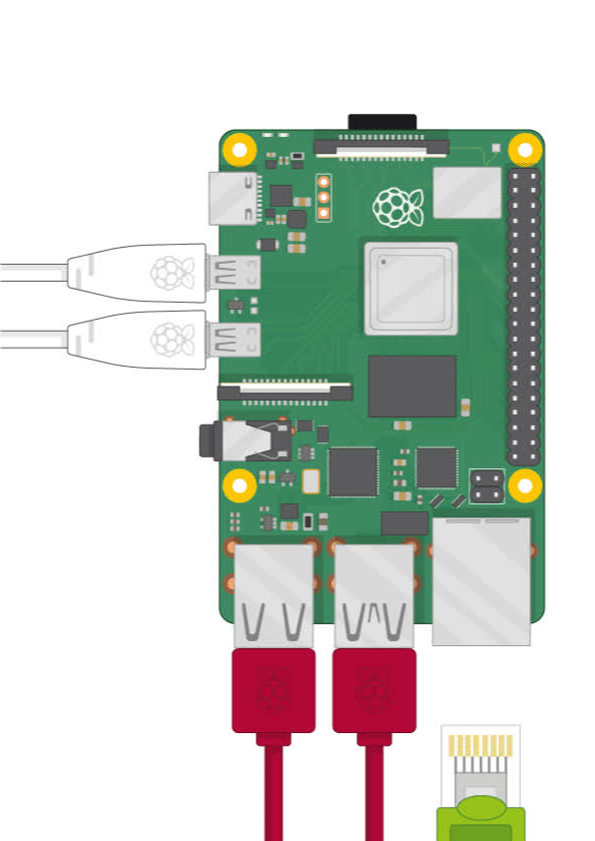
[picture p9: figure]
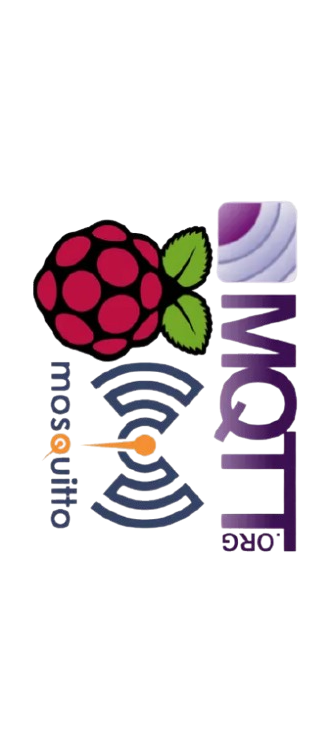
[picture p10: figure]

MQTT è la centrale operativa di LagmaBIlls in cui vengono scambiati tutti i messaggi e i comandi da inviare alle varie periferiche

L’indirizzo ip del raspberry è: 100.100.61.49 a cui si collegano tramite vari protocolli (es: http, websocket, ecc..)

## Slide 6

SIGMA & CO.

Search...

About

Project

Service

Team

Log In

The type of connections

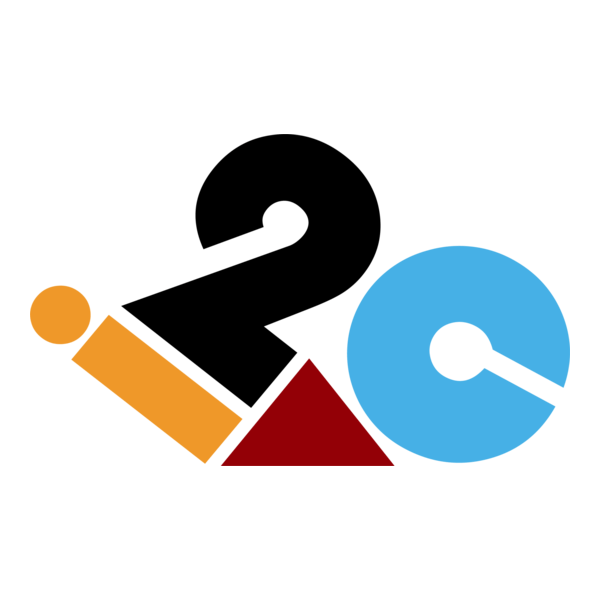
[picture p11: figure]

i2C / Bluetooth 5.0

Bluetooth 4.0 è il protocollo con cui lo stereo comunica con il raspberry, mentre i2c viene usato come protocollo di backup in caso si perda la connessione internet e per comunicare con una latenza minore per i comandi più necessari nell’immediato

01

Tailscale

La VPN di tailscale la utilizziamo per tutti i dispositivi che vogliono comunicare con LagmaBills per concedere l’accesso anche a grandi distanze e con bassa latenza

02

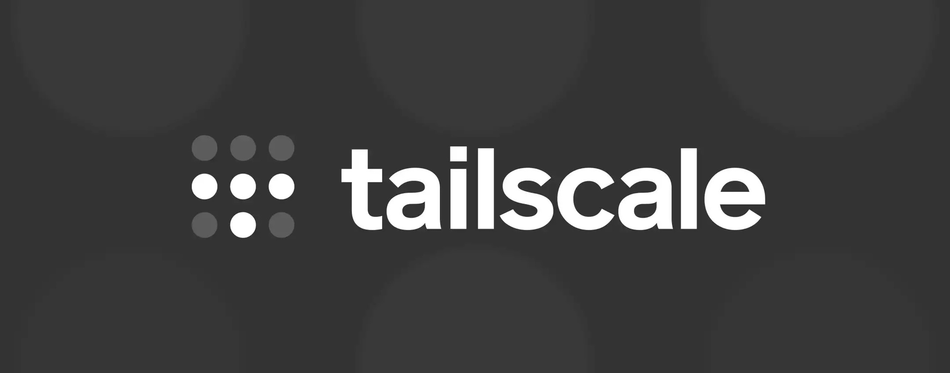
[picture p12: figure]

02

01

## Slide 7

Sigma & CO.

Search...

About

Project

Service

Team

Log In

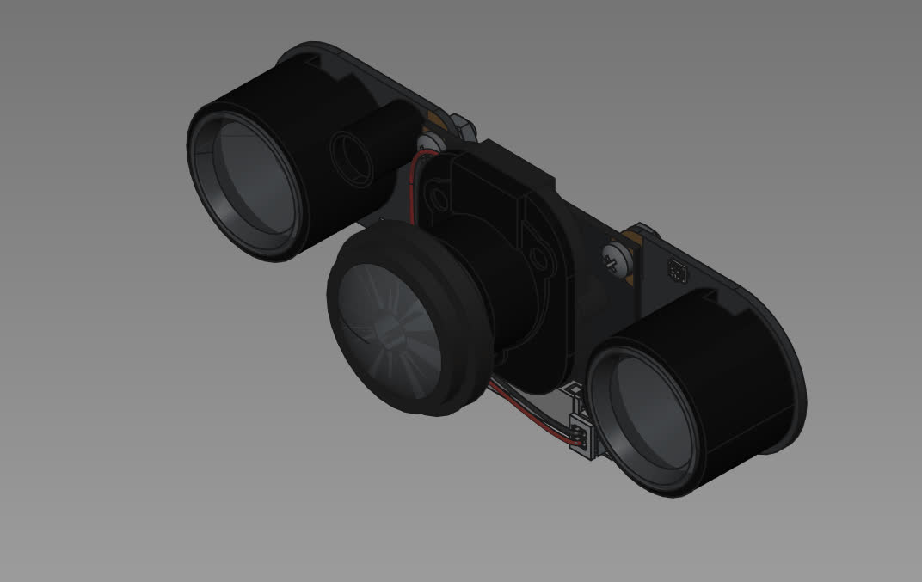
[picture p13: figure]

The Eyes and the Arm

Lagma BIlls interagisce con l’ambiente intorno a se grazie a una telecamera OV5647 IR-CUT 175deg che streamma il video all’applicazione di controllo e all’AI che studia il video, mentre il braccio ha 3 servo motori sg90 e 3 servo MG996R con cui può interagire fisicamente rimuovendo ostacoli e sollevar eoggetti

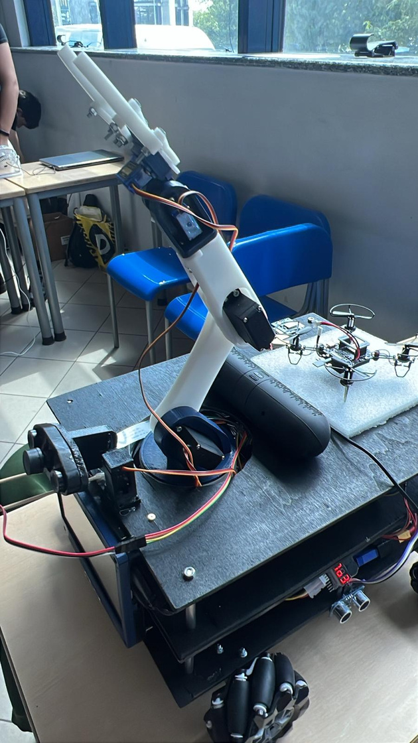
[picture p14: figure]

01

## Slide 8

Sigma & CO.

Search...

About

Project

Service

Team

Log In

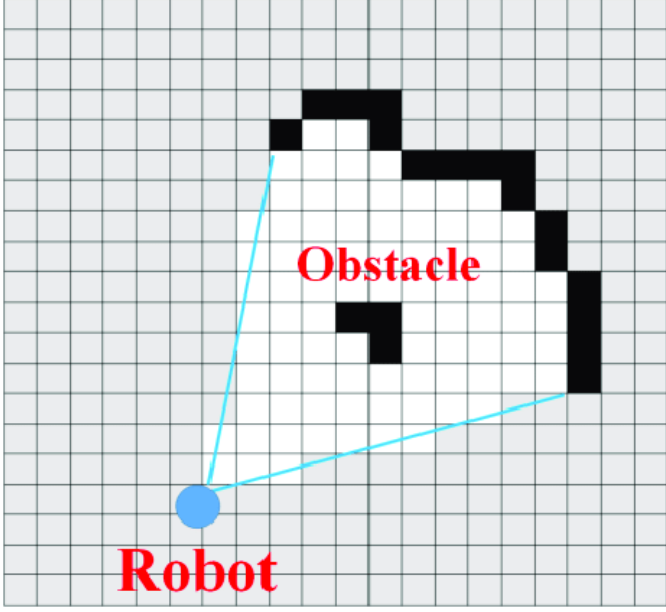
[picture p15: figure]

Odometry:

Tramite la tecnologia della odometria LagmaBills è in grado di riconoscere l’ambiente intorno a se e sapere come esplorarlo autonomamente senza la necessità del controllo manuale dell’uomo, questo grazie ai 6 sensori ad ultrasuoni che comprendono le distanze e il GPS che riconosce la posizione con la triangolazione della sua posizione comunicando con più satelliti in orbita possibili.

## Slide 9

SIGMA & CO.

Search...

About

Project

Service

Team

Log In

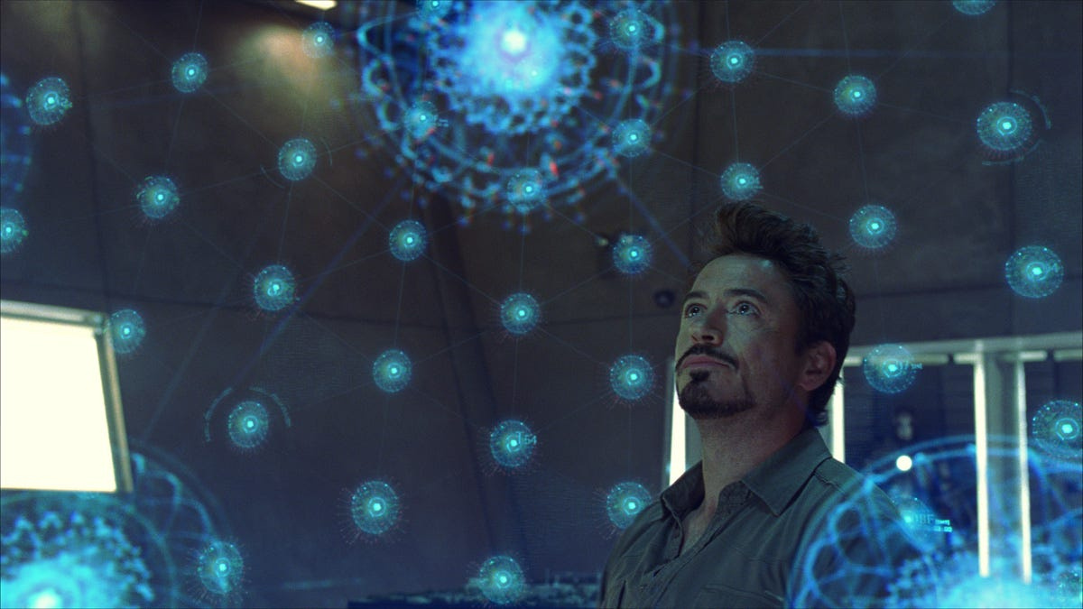
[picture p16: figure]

The Mind:

Lagmabills usufruisce dell’utilizzo di un intelligenza artificiale attraverso un server groq dove è possibile
utilizzarla fino a 1000 volte al giorno in termini di chiamate più precisamente utilizziamo un modello da 120 miliardi di parametri, lo abbiamo scelto perchè ha una velocità di risposta pari a 200ms

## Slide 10

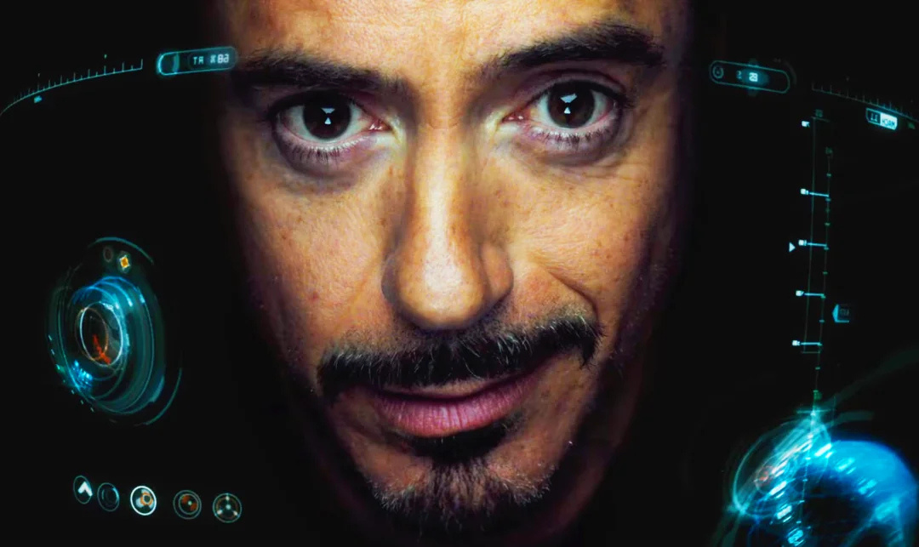
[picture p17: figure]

Service

Team

Log In

AI ARCHITECTURE

Esso è provvisto anche di una visione artificiale dove è in grado di capire la maggior parte degli oggetti che gli vengono posti davanti.
Abbiamo utilizzato Whisper per trasformare le voci delle persone in parole che l’IA è in grado di capire, e invece abbiamo usato piperTTS per creare una voce che il rasberry riproduce quando riceve cosa deve dire dall’intelligenza.

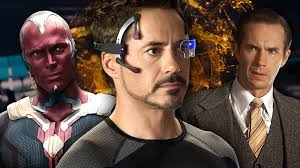
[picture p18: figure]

02

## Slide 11

SIGMA & CO.

Search...

About

Project

Service

Team

Log In

Why LagmaBills Can Fly?

01

Il drone esp32 fa da sonda di ricognizione come veicolo aereo per sondare zone non accessibili via terra.

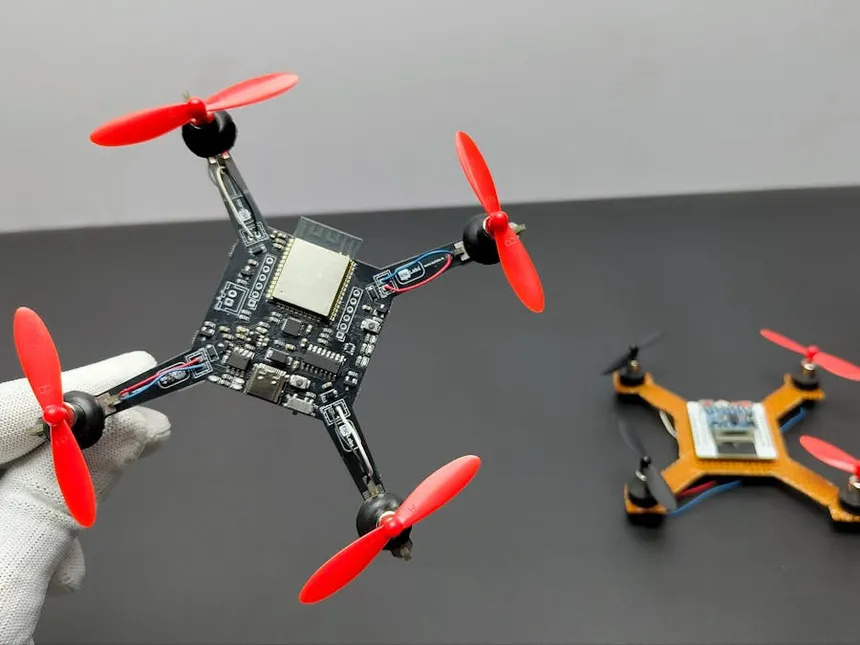
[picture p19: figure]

ESP32-Drone

02

Perchè precostruito?

Ne abbiamo utilizzato uno precostruito a causa dei costi elevati nello svilupparne uno da zero e per la complicatezza non necessaria per il suo scopo reale

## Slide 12

Thank You!

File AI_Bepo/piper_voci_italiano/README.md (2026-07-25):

---
license: cc-by-4.0
task_categories:
- text-to-speech
language:
- it
datasets:
- kirys79/piper_italiano
pipeline_tag: text-to-speech
---

# Piper Italiano

Sto cercando di creare nuove voci e nuovi checkpoint per PiperTTS in italiano.

La fonte per il train è il **[Multilingual LibriSpeech (MLS)](https://www.openslr.org/94/)** rilasciato sotto licenza Creative Commons

A questo [link](https://huggingface.co/datasets/kirys79/piper_italiano/) troverete i dataset estratti dalla suddetta fonte e messi nel formato richiesto per addestrare i modelli di [PiperTTS](https://github.com/rhasspy/piper).

I modelli in questo report saranno tutti forniti di checkpoint per permettervi di fare finetune
Lo speaker è lo speaker ID nel dataset di MLS
Il tipo indica se il modello è da zero (From Scratch o un Fine Tune)

| Nome | Tipo | Speaker | Note  |
| :----|---| ---:| :-----|
|Aurora | From Scratch | 6807 | Marcato accento - fa pause enfatiche...
|Leonardo| From Scratch | 1595 | Probabile voce di Riccardo (modello originale di piper) ma ad una maggiore qualità
|Giorgio| Fine Tune | 8181 | Esperimento di Fine tune basato su Leonardo

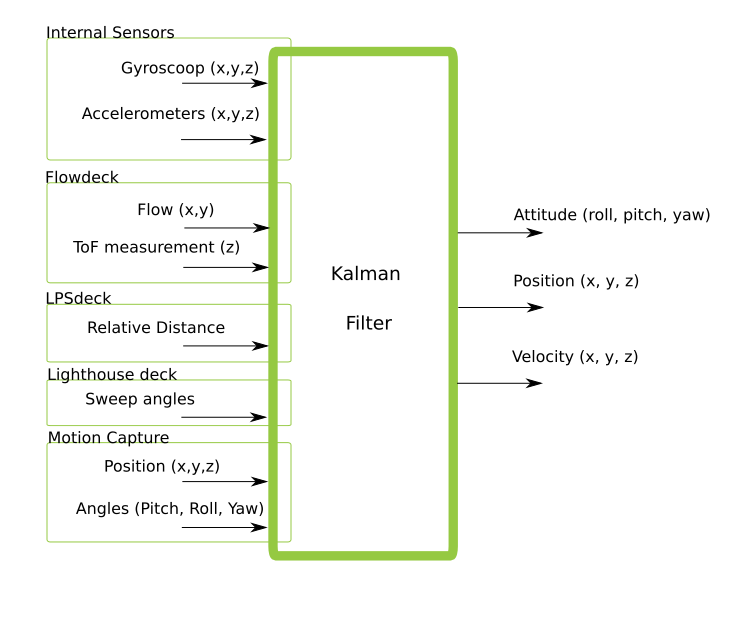
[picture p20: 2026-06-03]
raspberry/modules/Bamberg/ESP-IDF/esp-drone-master/docs/_static/Schematic-overview-of-inputs-and-outputs-of-the-Extended-Kalman-Filter.png

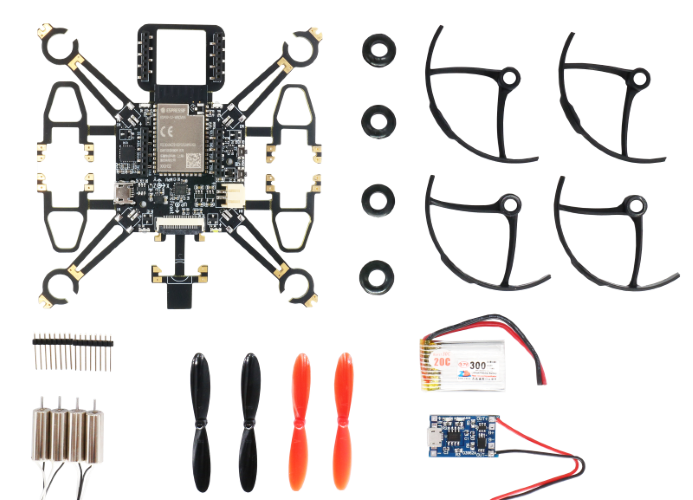
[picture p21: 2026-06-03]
raspberry/modules/Bamberg/ESP-IDF/esp-drone-master/docs/_static/espdrone_s2_v1_2_hardware_package.png

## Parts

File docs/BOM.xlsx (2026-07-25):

Componente | A cosa serve | Prezzo approssimativo (€)
Raspberry Pi 4B (4GB) | Unità centrale, orchestrazione, MQTT broker, AI vision, dashboard | 65 €
ESP32-WROOM-32 (x2) | Controllo motori (PCBmotori) e sensori/braccio (PCBsensori) | 16 €
PCB PCBmotori (custom, 4 layer) | Scheda controllo motori, encoder, I2C slave 0x08 | 20 €
PCB PCBsensori (custom, 2 layer) | Scheda sensori, servo, I2C slave 0x09 | 12 €
PCB PCBalim (custom, 2 layer) | Distribuzione alimentazione, protezione inversione polarità | 10 €
Motori JGA25-370 12V + encoder (x4) | Trazione ruote Mecanum con feedback odometria | 48 €
Ruote Mecanum (set x4) | Movimento laterale/rotazione robot | 35 €
Driver motore TB6612FNG (x2) | Pilotaggio motori DC da PWM ESP32 | 10 €
Sensore ultrasuoni HC-SR04 (x6) | Rilevamento ostacoli + rilevamento dirupo/cliff | 12 €
MPU-6050 (IMU) | Accelerometro + giroscopio per stabilità/orientamento | 4 €
Sensore di linea TCRT5000 (x3) | Modalità insegui-linea | 5 €
PCA9685 (driver servo 16 canali) | Controllo braccio robotico (6 servo) | 6 €
Servo MG996R (x3-4) | Giunti principali braccio (base, spalla, gomito) | 24 €
Servo SG90 (x2-3) | Giunti secondari braccio (polso, pinza) | 9 €
ReSpeaker 2-Mic HAT (WM8960) | Acquisizione audio, wake word, direzione arrivo voce | 25 €
Modulo GPS NEO-6M | Posizionamento world-frame, tracciamento su mappa | 10 €
Camera OV5647 (CSI) | Streaming video MJPEG, visione artificiale | 15 €
Display HDMI 7" | Interfaccia volto animato (RoboEyes) | 45 €
ESP-Drone (ESP32-S2) | Drone da ricognizione aerea, controllo CRTP/UDP | 55 €
Batteria LiPo 3S 5500mAh (x2) | Alimentazione robot + braccio | 50 €
Speaker Bluetooth | Uscita audio TTS, musica, sirene | 15 €
Relè pompa | Attivazione pompa (soccorso/civile) | 5 €
Cavi, connettori, resistenze varie | Cablaggio generale, partitori di tensione ECHO, pull-down | 20 €
Telaio/scocca (materiale stampa 3D) | Struttura fisica robot, supporti sensori/camera/drone | 30 €
TOTALE |  | 546 €

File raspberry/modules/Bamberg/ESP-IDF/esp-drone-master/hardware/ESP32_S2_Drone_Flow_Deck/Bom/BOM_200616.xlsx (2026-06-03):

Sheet: BOM
BOM V0.1
Item | Quantity | Reference | Value | Package | ICs | Description | Manufacturer | Manufacturer Part # | Notes
1 | 4 | 1C1,1C3,1C7,1C8 | 10uF/10V | C0603 | 陶瓷电容 | 陶瓷电容 | 未指定 | 未指定
2 | 9 | 1C2,1C4,1C6,2C1,2C2,2C3,2C6,1C10,1C11 | 0.1uF/10V | C0402 | 陶瓷电容 | 陶瓷电容 | 未指定 | 未指定
3 | 2 | 1C5,1C9 | 4.7uF/10V | C0603 | 陶瓷电容 | 陶瓷电容 | 未指定 | 未指定
4 | 1 | 2C5 | 4.7uF/10V | C0402 | 陶瓷电容 | 陶瓷电容 | 未指定 | 未指定
5 | 4 | 1J1,1J2,2J1,2J2 | CON8-S-2P0 | CON8-S-2P0 | 连接器 | 单排排母,8P,间距2.0mm,错位贴片,A型 | 长江连接器 | A2005HWV-S-8P-A
6 | 5 | 1R1,1R2,1R3,1R4,1R5 | 10K/1% | R0402 | 贴片电阻 | 贴片电阻 | 未指定 | 未指定
7 | 1 | 1U1 | PMW3901MB-TXQT | COB28_0P65_6X6 | 传感器IC | 光流传感器 | PixArt Imaging | PMW3901MB-TXQT | 需同时采购配套镜头
8 | 1 | 1U2 | ME6211C20M5G-N | SOT-23-5 | LDO IC | LDO,输出电压2.0V | 微盟电子 | ME6211C20M5G-N
9 | 1 | 1U3 | VL53L1CXV0FY/1 | LGA12_0P8_2P5X4P9 | 传感器IC | ToF传感器 | ST | VL53L1CXV0FY/1
10 | 1 | 2C4 | 0.22uF/10V | C0402 | 陶瓷电容 | 陶瓷电容 | 未指定 | 未指定
11 | 1 | 2U1 | HMC5833L | LPCC16_0P5_3X3 | 传感器IC | Compass传感器 | Honeywell | HMC5833L
12 | 1 | 2U2 | MS5611-01BA | QFN8_1P25_3X5 | 传感器IC | 气压传感器 | TE | MS5611-01BA

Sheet: Changelog
版本 | 改版内容 | 改版人 | 改版日期
V0.1 | 首版 | YXF | 2020-06-12

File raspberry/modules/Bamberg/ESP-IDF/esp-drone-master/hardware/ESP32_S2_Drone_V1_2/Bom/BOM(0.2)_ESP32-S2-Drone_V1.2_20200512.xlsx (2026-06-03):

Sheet: ESP32-S2-Drone
BOM(V0.2)_ESP32-S2-Drone_V1.2
ID | Qty | Ref Des | Value | Package | Description | Manufacturer | Manufacturer Part # | Notes
1 | 8 | C1,C3,C10,C11,C12,C14,C15,C16 | 10uF/10V | C0603 | 陶瓷电容
2 | 9 | C2,C4,C5,C7,C9,C17,C18,C19,C21 | 0.1uF/10V | C0402 | 陶瓷电容
3 | 2 | C6,C8 | 4.7uF/10V | C0603 | 陶瓷电容
4 | 1 | C13 | 470pF/25V | C0402 | 陶瓷电容
5 | 1 | C20 | 10nF/25V | C0402 | 陶瓷电容
6 | 1 | C22 | 2.2nF/25V | C0402 | 陶瓷电容
7 | 0 | C23,C24 | 0.1uF/10V(NC) | C0402 | 陶瓷电容 |  |  | 不贴件
8 | 4 | D1,D2,D4,D5 | 1N4148WT | SOD523 | 开关二极管 | 长电科技 | 1N4148WT
9 | 1 | D3 | BAT60B | SOD323 | 肖特基二极管 | Infineon | BAT60B
10 | 1 | D6 | LED-WHT | LED3010-S | LED,白色 | Everlight | 12-21/T3D-APQHY/2C
11 | 1 | D7 | LED-BLE | LED3010-S | LED,蓝色 | Everlight | 12-21/BHC-ZL2N1TY/2C
12 | 1 | D8 | LED-RED | LED3010-S | LED,红色 | Everlight | 12-21/R8C-AN1P2B/2D
13 | 1 | D9 | LED-GRN | LED3010-S | LED,绿色 | Everlight | 12-21/GHC-YQ1R1B18Y/2C
14 | 1 | FB1 | BLM18SG331TN1D | L0603 | 磁珠,330R at 100MHz,1A | Murata | BLM18SG331TN1D
15 | 1 | J1 | USB-MICRO-B | USB_5P_MICRO_F | USB MicroB 连接器,四脚插板,无柱,卷边
16 | 1 | J2 | FFC-24P | FFC24-0P5 | FPC连接器,24P,间距0.5MM,翻盖式,下接
17 | 4 | J3,J4,J10,J11 | CON8-S-2P54 | A2005HWV-S-XP-A | 单排排母,8P,间距2.0mm,错位贴片,A型 | 长江连接器 | A2005HWV-S-8P-A
18 | 0 | J5,J6,J8,J9 | CON2-SB-ZH(NC) | CON2X1_1P5_SMT_ZH-2A_DIP | 针座,2P,ZH,侧入贴片 |  |  | 不贴件
19 | 1 | J7 | CON2-SB-PH | CON2X1_2P0_SMT_PH2A-S-A | 针座,2P,PH,侧入贴片
20 | 1 | Q3 | AO3401A | SOT-23-3 | PMOS | AOS | AO3401A
21 | 4 | Q4,Q5,Q6,Q7 | IRLML6344TRPbF | SOT-23-3 | Power NMOS | Infineon | IRLML6344TRPbF
22 | 3 | R1,R3,R6 | 0R/1% | R0402 | 贴片电阻
23 | 19 | R5,R8,R11,R12,R13,R14,R15,R16,R21,R22,R23,R24,R25,R27,R28,R32,R33,R34,R35 | 10K/1% | R0402 | 贴片电阻
24 | 1 | R7 | 22.1K/1% | R0402 | 贴片电阻
25 | 1 | R9 | 47.5K/1% | R0402 | 贴片电阻
26 | 3 | R10,R17,R19 | 82K/1% | R0402 | 贴片电阻
27 | 1 | R18 | 52.3K/1% | R0402 | 贴片电阻
28 | 1 | R20 | 29.4K/1% | R0402 | 贴片电阻
29 | 4 | R26,R29,R30,R31 | 1.5K/1% | R0402 | 贴片电阻
30 | 2 | SW1,SW2 | Button-3X3.5 | SW4_3X3P5X1P1_SMT | 轻触开关,侧按贴片,3mmX3.5mm | ALPS | SKSCLBE010
31 | 1 | U1 | USBLC6-2SC6 | SOT23-6 | ESD二极管 | ST | USBLC6-2SC6
32 | 1 | U2 | ME6211C28M5G-N | SOT-23-5 | LDO,2.8V | 微盟 | ME6211C28M5G-N
33 | 1 | U3 | CP2102N-A02 | QFN28_0P5_5 | USB to UART IC | Silicon Labs | CP2102N-A02
34 | 1 | U4 | ME6211C15M5G-N | SOT-23-5 | LDO,1.5V | 微盟 | ME6211C15M5G-N
35 | 1 | U5 | SGM2205-ADJ | DFN3030-8 | LDO,可调 | 圣邦微 | SGM2205-ADJ
36 | 1 | U6 | ESP32-S2-WROVER | ESP32-S2-WROVER | WiFi Module | Espressif | ESP32-S2-WROVER
37 | 1 | U7 | MPU-6050 | QFN24_0p5_4_A | 6轴运动传感器IC | InvenSense | MPU-6050
38 | 1 | U8 | BC847BDW1T1G | SOT363 | NPN Transistor,双路 | ON Semi | BC847BDW1T1G
39 | 1 | 非贴片物料 | 无人机锂电池 | NA | 动力型,300mAh,PH2.0,正向 |  |  | 参考链接 https://m.tb.cn/h.V8gEksR?sm=858897
40 | 4 | 非贴片物料 | 空心杯电机 | NA | 尺寸716,电压3.7v,50000转 |  |  | 参考链接 https://m.tb.cn/h.VR4sgSA?sm=2d0222
41 | 2 | 非贴片物料 | 螺旋桨A | NA | 尺寸46mm,0.75mm孔径,A螺旋桨 |  |  | 参考链接 https://m.tb.cn/h.VinQLQu?sm=185f2b
42 | 2 | 非贴片物料 | 螺旋桨B | NA | 尺寸46mm,0.75mm孔径,B螺旋桨 |  |  | 参考链接 https://m.tb.cn/h.VinQLQu?sm=185f2b
43 | 4 | 非贴片物料 | 电机密封圈 | NA | 孔径7mm,黑色 |  |  | 参考链接 https://m.tb.cn/h.VRfYUIN?sm=1dbc9d

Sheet: Sheet2
39 | 1 | NA | 无人机锂电池 | NA | 动力型300mah PH2.0 正向 | 参考链接 https://m.tb.cn/h.V8gEksR?sm=858897
40 | 4 | NA | 空心杯电机 | NA | 尺寸716 电压3.7v 50000 | 参考链接 https://m.tb.cn/h.VR4sgSA?sm=2d0222
41 | 2 | NA | 螺旋桨A | NA | 尺寸46mm 0.75mm孔径 A螺旋桨 | 参考链接 https://m.tb.cn/h.VinQLQu?sm=185f2b
42 | 2 | NA | 螺旋桨B | NA | 尺寸46mm 0.75mm孔径 B螺旋桨 | 参考链接 https://m.tb.cn/h.VinQLQu?sm=185f2b
43 | 4 | NA | 电机密封圈 | NA | 7mm孔径黑色 | 参考链接 https://m.tb.cn/h.VRfYUIN?sm=1dbc9d

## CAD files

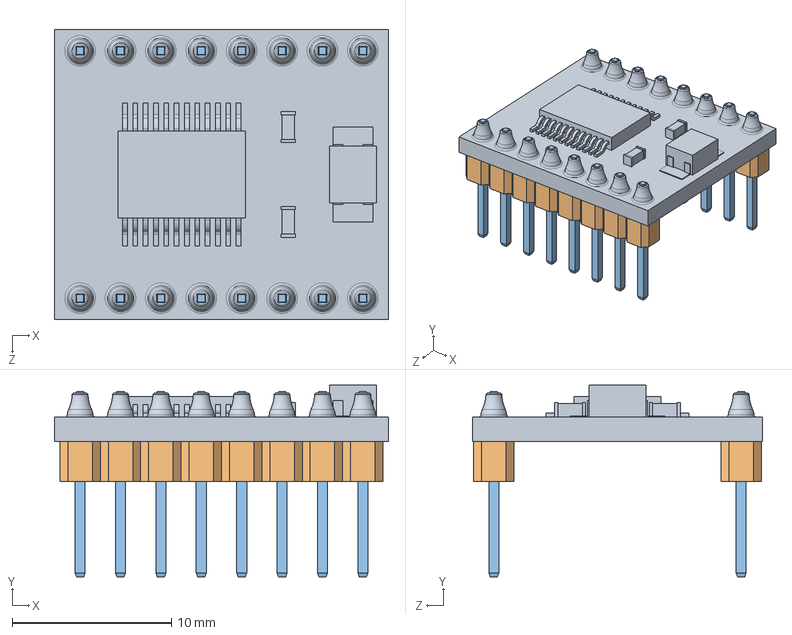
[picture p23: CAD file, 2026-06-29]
models_3d/Solidworks 2022/TB6612FNG.SLDASM
21.0 x 12.1 x 18.2 mm
Base
Основание пина x 16
Пин x 16

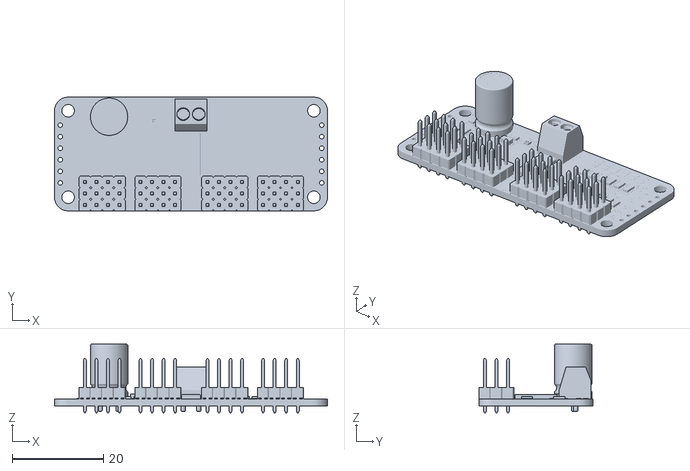
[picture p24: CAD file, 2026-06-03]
AmazingArm/PCA9685.stl
60.0 x 25.0 x 15.1

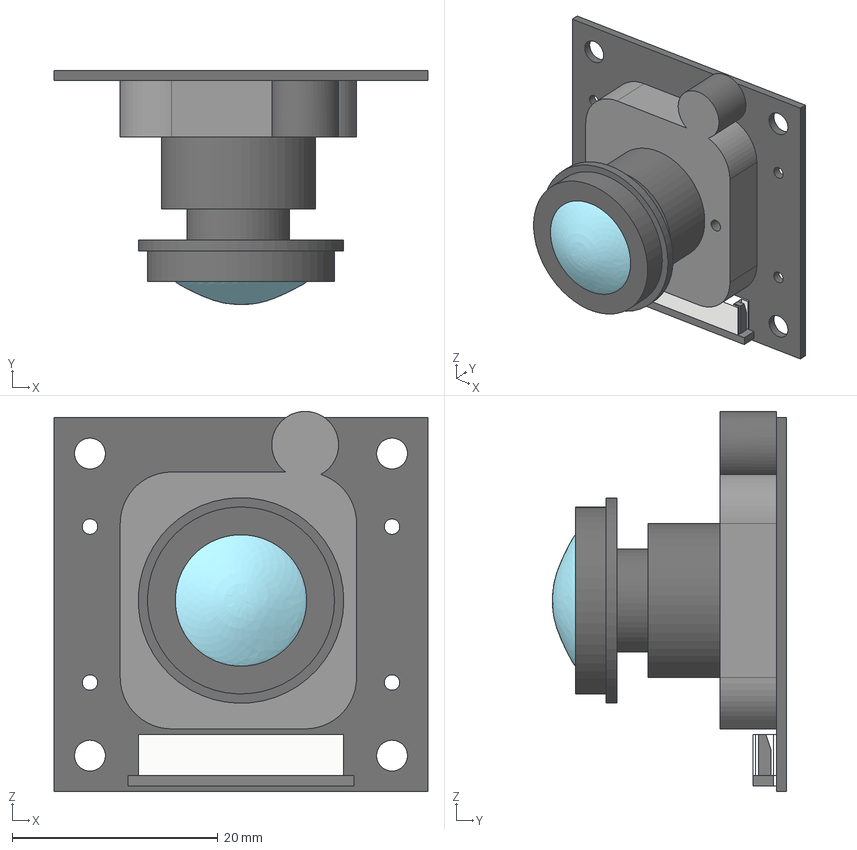
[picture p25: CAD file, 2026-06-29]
models_3d/ADRUCAM - IR CAMERA OV5647 (FISHEYE)/STEP/ADRUCAM - IR CAMERA (FISHEYE) v1.step
36.4 x 22.8 x 37.0 mm
FISHEY (GLASS)
CONNECTION (1)
CONNECTION (2)

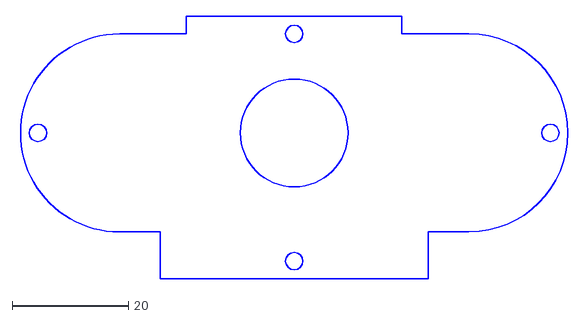
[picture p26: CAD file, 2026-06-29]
models_3d/Cases3Dmodels/camera/files/laser_3mm_acrylic.dxf
94.8 x 45.0

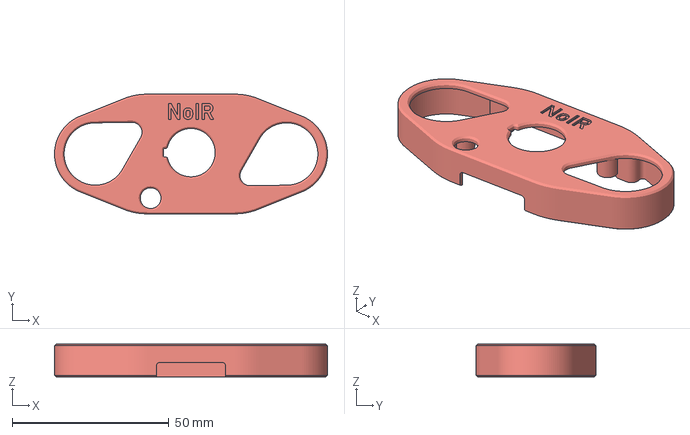
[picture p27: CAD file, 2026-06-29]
models_3d/Cases3Dmodels/camera/gnegne/3DP Files/top-body.3mf
87.0 x 38.1 x 10.5 mm

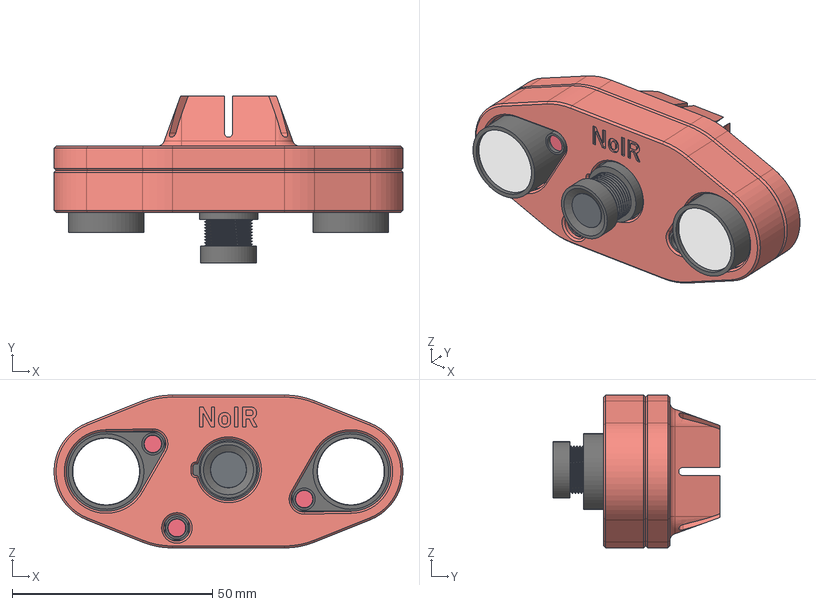
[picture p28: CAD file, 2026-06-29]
models_3d/Cases3Dmodels/camera/gnegne/CAD Files/noir-camera-housing-v13.step
87.0 x 41.6 x 38.2 mm
Top Body
raspicamback v4

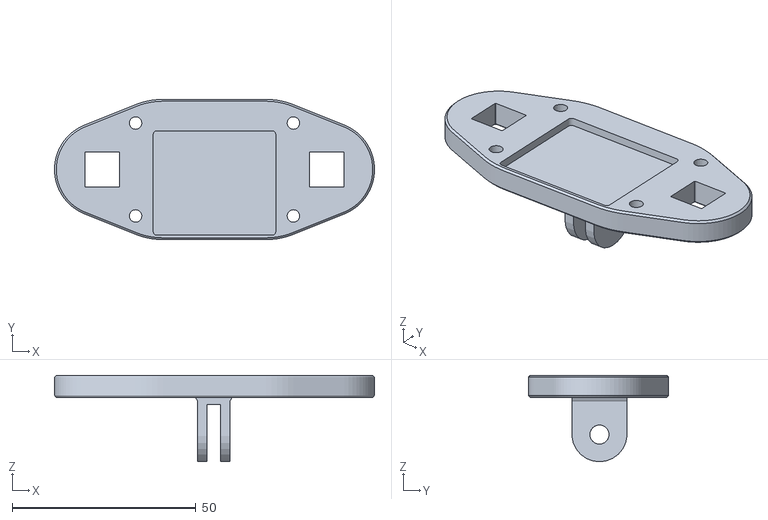
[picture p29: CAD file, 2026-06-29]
models_3d/Cases3Dmodels/camera/gnegne/Noir-Camera-Housing.stl
87.0 x 38.2 x 23.5

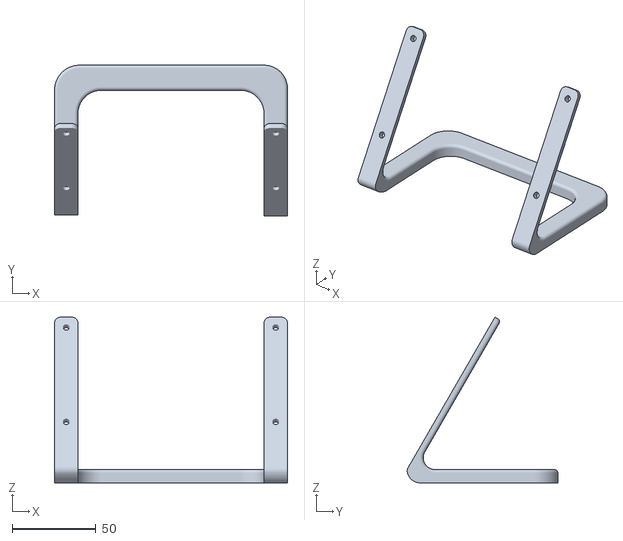
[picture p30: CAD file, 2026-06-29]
models_3d/Cases3Dmodels/files/Pi_7_inch_display_mount.stl
139.0 x 89.9 x 98.9

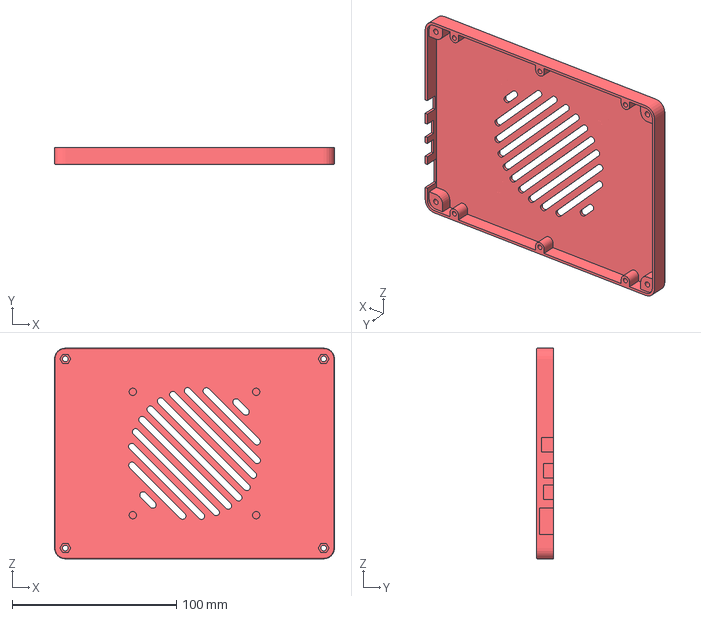
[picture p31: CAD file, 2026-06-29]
models_3d/Cases3Dmodels/screen-touch-7-back.3mf
170.3 x 10.2 x 128.2 mm

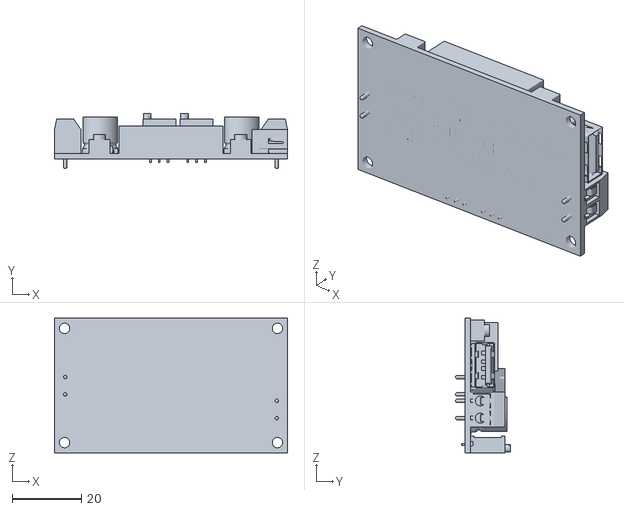
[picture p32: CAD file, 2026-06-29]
models_3d/JACOBSPARTS-XL4015.stl
67.3 x 15.9 x 38.9

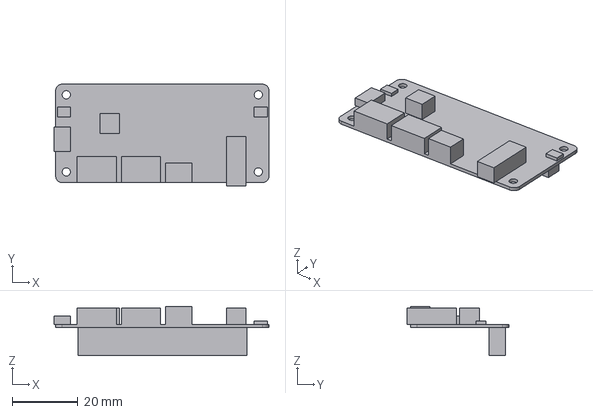
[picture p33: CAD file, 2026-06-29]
models_3d/Raspeaker/Respeaker2MicPiHat.step
65.5 x 31.0 x 15.0 mm

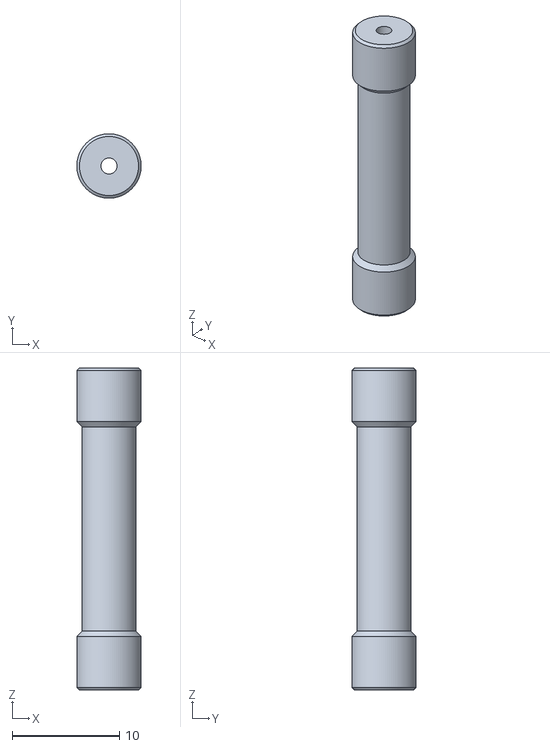
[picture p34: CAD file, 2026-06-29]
models_3d/skibidiTinkerCaz/obj_14_Standoff.step.stl
6.00 x 6.00 x 30.0

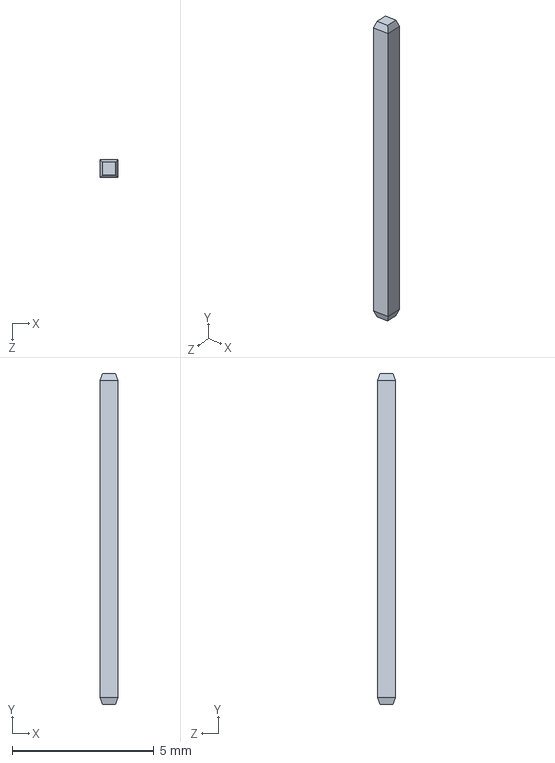
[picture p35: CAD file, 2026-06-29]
models_3d/Solidworks 2022/Пин.SLDPRT
0.64 x 11.7 x 0.64 mm

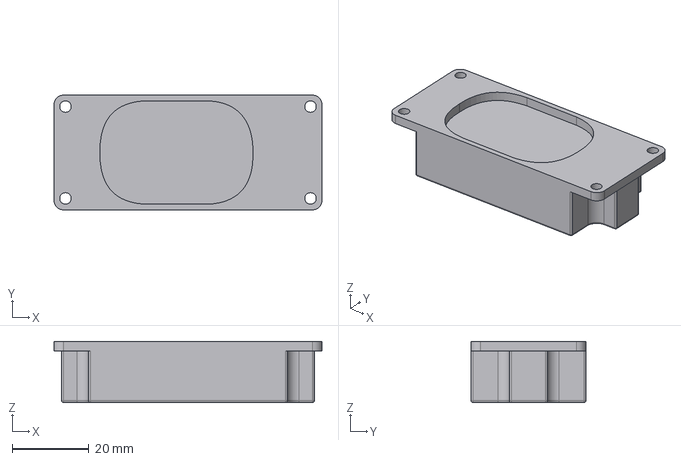
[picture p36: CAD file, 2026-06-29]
models_3d/speaker/AdafruitMonoEnclosedSpeaker3W.step
70.0 x 30.0 x 16.0 mm

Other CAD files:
models_3d/skibidiTinkerCaz/robot arm/obj_10_Standoff.step.stl
models_3d/STEP/TB6612FNG_Upper Pins.STEP
models_3d/stp/ICY-BOX - IB-RPA101 (60522).stp
PCB/PCBalim/XT90PW-F--3DModel-STEP-455599.STEP
PCB/PCBsens/PCBsens.stl
models_3d/3mf/ICY-BOX - IB-RPA101 (60522).3mf
models_3d/5787617-2.STEP
models_3d/5787617-2.stl
models_3d/6.ESP-32.SLDPRT
models_3d/ADRUCAM - IR CAMERA (FISHEYE) v1.stl
models_3d/Cases3Dmodels/GY-NEO6MV2-withAnt v2.step
models_3d/Cases3Dmodels/GY-NEO6MV2-withAnt v7.step
models_3d/Cases3Dmodels/GY-NEO6MV2-withAnt v7.stl
models_3d/Cases3Dmodels/KCD4_ROCKET_SWITCH.SLDPRT
models_3d/Cases3Dmodels/KCD4_ROCKET_SWITCH.STEP
models_3d/Cases3Dmodels/KCD4_ROCKET_SWITCH.stl
models_3d/Cases3Dmodels/RaspCamPrint.stl
models_3d/Cases3Dmodels/Raspberry_Display_case_1.stl
models_3d/Cases3Dmodels/camera/files/Camera_waterproof_housing.3dm
models_3d/Cases3Dmodels/camera/files/TPU_gasket.stl
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

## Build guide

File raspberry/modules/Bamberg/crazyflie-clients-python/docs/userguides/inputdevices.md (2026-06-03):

---
title: Input-devices for the Crazyflie client
page_id: inputdevices
---

The Crazyflie graphical control client needs an input-device (joystick)
with a minimum of 4 analogue axes to be able to pilot the Crazyflie. The
Playstation 3 controller is supported out of the box but the application
supports creating new configurations that uses other controllers. This
page details what controllers are supported out of the box, how to
create a new configurations and how to debug problems.

---

## Steps to get the controller working

Here\'s a few steps that you have to go though in order to get the
input-device working. If any of the steps are not working then the
input-device will not be usable for piloting the Crazyflie:

-   The input-device needs to be recognized by the host operating
    system. This means that it should be seen in the operating system
    and be usable in other applications or utilities.
-   When using the Crazyflie graphical control client you need at least
    the correct mappings for roll/pitch/yaw/thrust. This can be checked
    by opening the *Flight Data* tab. If the input-device is found and
    opened then you should see values in the *Target* fields for
    *Roll*,*Pitch*,*Yaw* and *Thrust*. Moving the analogue axis should
    show you output here. Make sure that you get the full span according
    to the settings on the left side of the tab. I.e if the setting for
    *Max roll/pitch* is 20 then you should be able to get from -20 to +
    20 in the target field (and the same for yaw and thrust). Also make
    sure that none of the axis interact (like moving roll will also move
    pitch).
-   If you aren\'t getting any output at all and you are using the
    Playstation 3 controller, then press the \"Playstation\" button in
    the middle on the controller once.
-   If the mappings are not correct in the previous point go to the menu
    *Input-device-\>Configure device mapping*, select the device you
    would like to configure and go though the configuration by clicking
    detect on each of the items in the dialog (everything has to be
    configured). Lastly enter the name of the configuration (without
    file extension) and press save. Now restart the application and try
    again.
-   It can happen be that another USB device other than your controller is recognized. Then it might be necessary to blacklist the USB device in the cfclient's config.json file. Check out [the config file explanation](/docs/development/dev_info_client.md#user-configuration-file)

---

## Input device overview

Below is a list of controllers and the status for different OSs. The
list is far from complete so if you have more info please edit or drop
us an email.

 | **Controller**    | **Linux USB** |   **Linux BT** |**Win XP USB**  | **Win XP BT**  |**Win7 USB**     |   **Win7 BT** |  **Win8 USB** |**Win10 USB** | **Win 11 USB** | **Mac OSX USB**  | **Mac OSX BT**|
|--|--|--|--|--|--|--|--|--|--|--|--|
 | Playstation 3 (or copy)  | Works  | Works |  Works |  Works | Works  | Works  | Works,  | Works | Not tested | Works   |  Works|
  Xbox 360 (or copy)   |  Works  | N/A  | Works    |   N/A    |   Works    |    N/A  |  Works | Works | Works| Not tested    |  Not tested|

### Playstation 3 controller

#### Linux using Bluetooth

[How to set up Sixaxis on
Ubuntu](https://help.ubuntu.com/community/Sixaxis) (tested on Ubuntu
13.10)

#### Win7 using USB

There\'s support for this using MotionJoy, **but** the mapping of the
axis is not the same as for Windows XP/Linux and has to be configured.
**TODO** Insert instructions for re-mapping.

[Video on how to get started with
MotionJoy](http://youtu.be/b2lUxNShIDs).

#### Win7 using Bluetooth

Should work using MotionJoy but this needs confirmation.

#### Win8 USB
[Instructions](http://www.wikihow.com/Set-Up-USB-Game-Controllers-on-Windows-8)

#### Mac OSX with Bluetooth

To pair the controller follow the steps outlined
[here](https://gist.github.com/statico/3172711). **TODO**: This
procedure is somewhat shaky. Figure out and add a solid set of steps
here.

**NOTE**: To shut down the controller you need to disconnect the
controller from OSX. This is easiest done if you enable in in System
Preferences -\> Bluetooth enable Show Bluetooth status in menu bar. From
the menu bar item you can easily disconnect it.

---

### Xbox 360 controller

#### Linux using USB

**INFO:** All modern Linux distribution now have a kernel driver for the x-box
gamepad. Thus it is unlikely the *xboxdrv* user-space driver is needed.

If you are having problems getting this to work the userspace driver
`xboxdrv` might be needed. It can be installed (on Ubuntu) by running:

    sudo apt-get install xboxdrv

And then started by running:

    sudo xboxdrv

More info about the `xboxdrv` is available
[here](https://xboxdrv.gitlab.io/).

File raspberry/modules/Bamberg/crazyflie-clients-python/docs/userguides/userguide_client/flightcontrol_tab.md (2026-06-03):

---
title: Flightcontrol Tab
page_id: flightcontrol_tab
sort_order: 1
---

The normal view used when flying is the one seen below.

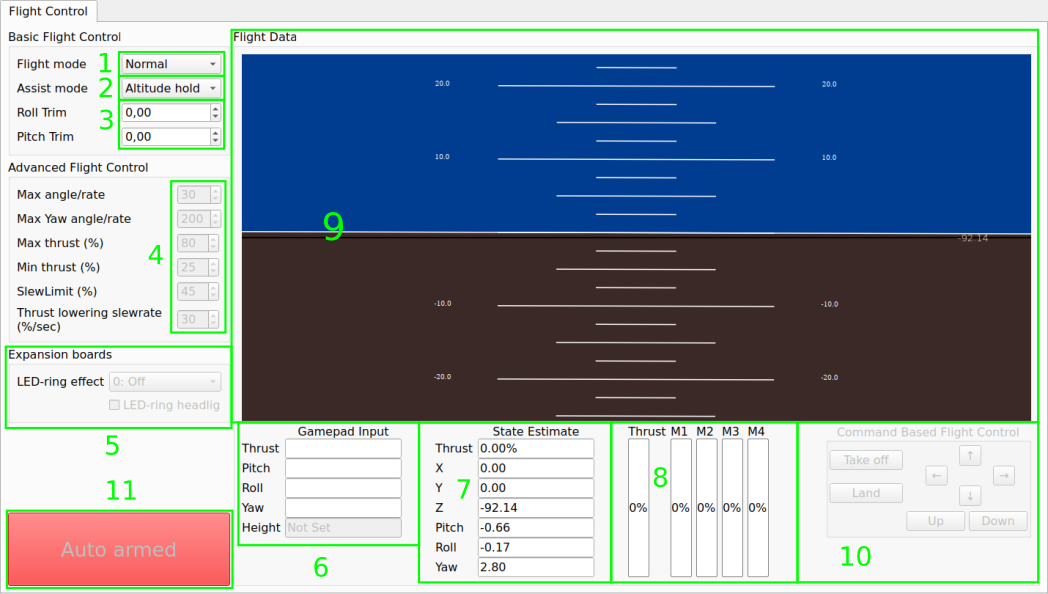
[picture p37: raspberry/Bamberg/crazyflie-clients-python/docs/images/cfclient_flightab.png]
cfclient flighttab


1.  Flight mode selector (Normal and Advanced)
    * *Normal:* Recommended for beginners
    * *Advanced:* Will unlock flight settings in 3

2.  Assisted mode selection. The assisted mode is enabled when the assisted mode
    button is pressed on the Gamepad.
    * *Altitude hold*: Keeps the Crazyflie at its current altitude automatically. Thrust control becomes height velocity control.
    * *Position hold*: Keeps the Crazyflie at its current 3D position. Pitch/Roll/Thrust control becomes X/Y/Z velocity control.
    * *Height hold*: When activated, keeps the Crazyflie at 40cm above the ground. Thrust control becomes height velocity control. Requires a height sensor like the [Z-Ranger deck](https://www.bitcraze.io/products/z-ranger-deck-v2/).
    * *Hover*: When activated, keeps the Crazyflie at 40cm above the ground and tries to
    keep the position in X and Y as well. Thrust control becomes height velocity
    control. Requires a flow deck. Uses body-fixed coordinates.
3. Roll/pitch trim can be set either in the UI or using the controller (if the correct buttons are mapped).
    This will offset the input to the Crazyflie for correcting imbalance and reducing drift.
4. Advanced flight control settings are available if Advanced mode has been selected (settings are in %):
    * *Max angle:* Set the max roll/pitch angle allowed
    * *Max yaw rate:*Set the max yaw rate allowed
    * *Max thrust:* Set the max thrust allowed
    * *Min thrust:* Minimum thrust before 0 is sent to the Crazyflie
    * *Slew limit:* Set the percentage where the thrust is slew controlled (the thrust value lowering will be limited). This makes the Crazyflie a bit easier to fly for beginners
    * *Slew rate:* When the thrust is below the slew limit, this is the maximum rate of lowering the thrust
5. Settings for flight decks, currently the LED-ring effect and headlights can be set (if the ring is attached)
6. Target values sent from the client for controlling the Crazyflie
7. Actual values logged from the Crazyflie
8. Motor output on the Crazyflie
9. Horizon indicator
10. Command based flight control, allow controlled flight if, and only if, a positioning deck such as the [Flow deck](https://store.bitcraze.io/collections/decks/products/flow-deck-v2), the [Loco deck](https://store.bitcraze.io/collections/decks/products/loco-positioning-deck) or the [Lighthouse deck](https://store.bitcraze.io/collections/decks/products/lighthouse-positioning-deck) is present.
11. Arming/disarming button. Pressing this will send a arming or disarming event to the Crazyflie which will arm or disarm the system if this is possible. This button can also say "Auto arming" which indicates the crazyflie is configured to arm the system automatically if system checks have passed. More info in [crazyflie firmware arming documentation](https://www.bitcraze.io/documentation/repository/crazyflie-firmware/master/functional-areas/supervisor/arming/).

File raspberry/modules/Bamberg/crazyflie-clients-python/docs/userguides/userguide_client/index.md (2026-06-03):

---
title: Userguide cfclient GUI
page_id: userguide_client
sort_order: 1
---

This page is intended to give an overview on how to use the Crazyflie
client, not for installing it. For install instructions go
[here](https://github.com/bitcraze/crazyflie-clients-python/blob/develop/README.md).

The Crazyflie client is used for controlling the Crazyflie, flashing
firmware, setting parameters and logging data. The main UI is built up
of a number of [tabs](index.md#tabs-and-toolboxes), where each tab is used for a specific
functionality.

This page uses the terms
[roll/pitch/yaw](http://en.wikipedia.org/wiki/Flight_dynamics_(fixed_wing_aircraft))
extensively. For that to make any sense for a quadcopter we need to know
where the front is, so you will need to know [Crazyflie's coordinate system](https://www.bitcraze.io/documentation/system/platform/cf2-coordinate-system/)

---

## How to get flying with a controller

-   Start up the application
-   Insert the joystick and Crazyradio (PA)
-   Before you connect to the Crazyflie make sure that the joystick is
    working as expected and that the **thrust is zero**. The joystick
    values should be visible in the flight data box under target.
-   Press *Scan*
-   Wait for the scanning to complete
-   In the drop-down menu to the left of the Connect button select the
    Crazyflie you want to connect to. Connect to the URI e.g.
    radio://0/80/250k.
-   The client will now connect to the Crazyflie and handshake
-   When the handshake is done you can start flying the Crazyflie.
    Remember the most tricky part is the thrust so start out easy\...

For more info on LED indicators etc. have a look at the [Crazyflie 2.X](https://www.bitcraze.io/documentation/tutorials/getting-started-with-crazyflie-2-x/#understanding-leds) user guide.

---

## Main UI

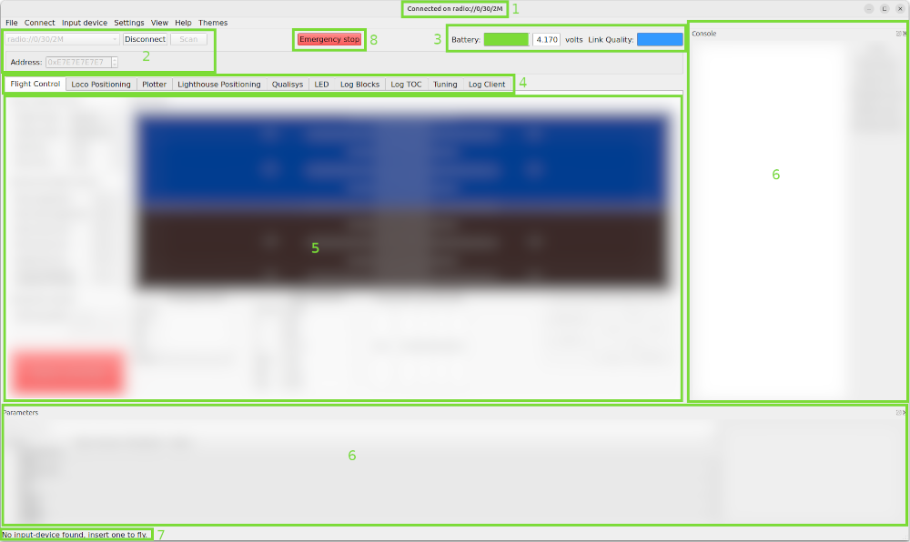
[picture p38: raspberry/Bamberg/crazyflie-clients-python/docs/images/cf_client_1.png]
CF client main


1.  The window title will show the connection status
2.  Connect/disconnect, scan and the drop-down connection list as well
    as Address and auto reconnect.
       * *Scan:* Will scan for availible Crazyflies within the chosen address.
       * *Connect:* Will connect to the selected URI in the connection list
       * *Disconnect:* Will disconnect the current Crazyflie
       * *Address:* The address to scan for. If you didn't change this [in the configuration]( #firmware-configuration), then leave the default of 0xE7E7E7E7E7
3. Battery and link quality (from 0% to 100%)
4. Tabs with specific functionality (see below for details)
5. The content for the active tab
6. Toolboxes can be docked to the edges, making their content visible all the time.
7. The selected and used input interface
8. Emergency stop button. The motors will stop when clicked.

### Tabs and toolboxes

The main interface is built up of different tabs that can be shown/hidden from the *View-\>Tabs* menu. The tabs can
also be used as toolboxes, that is small windows that can be docked to the sides of the main window. This makes it possible
to display multiple windows at the same time, the console log can for instance be visible as a toolbox at the same time
as the parameter tab is open to set a value. To open a toolbox, use the *View-\>Toolboxes* menu, if the toolbox is
already open as a tab, the tab will be removed and it will be opened as a toolbox instead.

The following tabs/toolboxes are currently available:

{% sub_page_menu %}
---

## Functionality

Below are a few guides on how to accomplish specific tasks with the
client.

### Firmware upgrade

For updating the Crazyflie firmware you can keep being connected to the crazyflie. This will open up a separate dialog
that will guide you through the process.

Please note that you need to use a Crazyradio dongle to connect to the Crazyflie when doing firmware upgrades.
Upgrading using USB is **not** possible.

#### Deck firmware

Some decks have a CPUs or other chips that runs firmware that needs to be updated from time to time as well. The Crazyflie
firmware verifies that it is compatible with the deck firmware during start up. If the firmware in a deck that is
installed needs to be upgraded this will be logged in the console log. Deck firmware is upgraded as a part of the
Crazyflie firmware upgrade process, just make sure the deck is mounted when you run the upgrade.

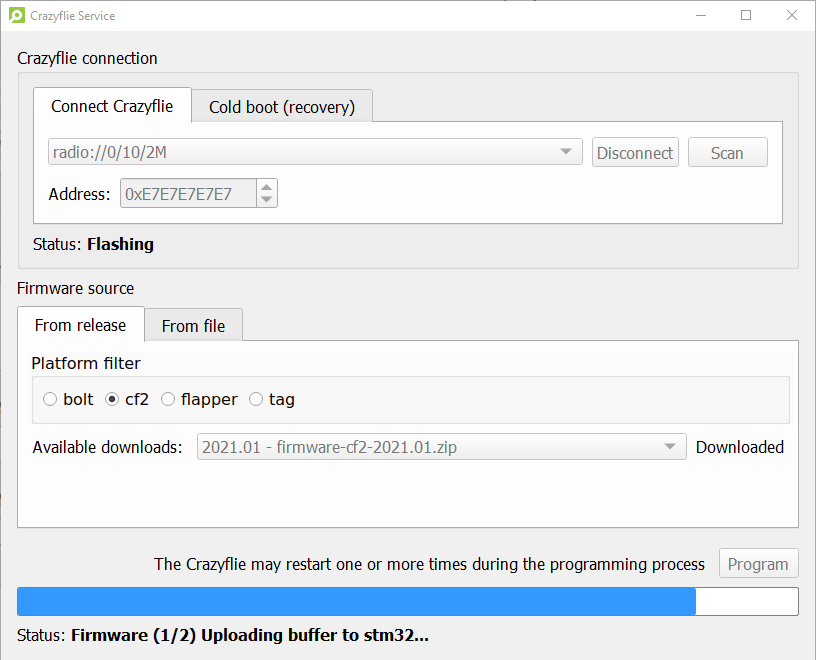
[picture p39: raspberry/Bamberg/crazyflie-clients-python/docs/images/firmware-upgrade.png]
CFclient bootloading


To update the firmware in the Crazyflie 2.X do the following:

-   Make sure to have any decks you will be using attached during the update, since some of
the decks contain their own firmware which will also be updated during the firmware update. Also make sure there is a battery attached.
-   Go to the menu *Connect-\>Bootloader*
-   Connect to the crazyflie in this dialog, if it is not already connected in the flighttab.
-   Chose what to flash
    - Use the "From release" tab to automatically use an [official release](https://github.com/bitcraze/crazyflie-release/releases). Make sure to select the right platform (cf2 is the Crazyflie 2.X)
    - Use the "From file" tab if you have some other release file you want to flash.
-   Click \"Program\" and wait for both the STM, NRF and decks to be flashed. Note: the Crazyflie may restart multiple times during this process.
-   Your crazyflie will automatically restart a couple of times.
-   Do not touch or restart your crazyflie untill all flashing is done and you see \"status: idle\" at the bottom.
- To check the firmware version, under the *View* menu, open up *Tabs-\>Console* tab and look at the output when connecting to the
Crazyflie 2.X.

If you accidently restarted your crazyflie during flashing or anything else happend which caused your crazyflie to not start up properly, follow [the instructions for recovery mode](/docs/userguides/recovery-mode.md).

### Firmware configuration

It is possible to set another channel to communicate with the Crazyflie 2.X. It can be wise to do this if there exist other wireless
networks that can interfere, especially WiFi. It is also possible to
permanently store the trim values for pitch and roll.

It is currently possible to change the following parameters which are
stored in a none volatile memory:

-   **Pitch trim** Can be programmed permanently with the trim values
    found to work good in the flight tab.
-   **Roll trim** Can be programmed permanently with the trim values
    found to work good in the flight tab.
-   **Radio channel** Can be set to anything between 0 and 125,
    correspond to a frequency from 2400MHz to 2525MHz. In most countries
    channel 0 to 80 is OK to use but this should be checked with you
    local regulations. If using 2M datarate, the copter channels should
    be 2 apart (2MHz).
-   **Radio bandwidth** This can set the radio bandwidth to 250k, 1M or
    2M. A lower bandwidth has longer range but has higher chance of
    collision. When used inside sometimes it is better to use 1M or 2M
    as it decreases the risk of collision with WiFi.
-   **Radio address** (advanced) will set the shock burst address used
    for communicating. Note that if you change this then you will have
    to set the address correctly in the connect dialog.

The procedure is described below and the parameters can be changed again
any time the same way.

First connect to the Crazyflie 2.X with the normal connect button. Then open "Connect->Configure 2.X" to reach the configure 2.X dialog

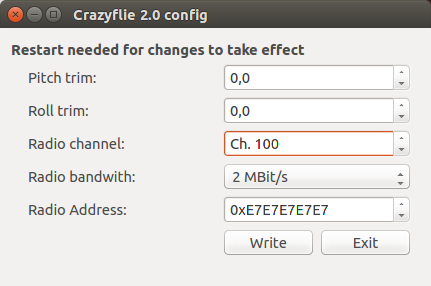
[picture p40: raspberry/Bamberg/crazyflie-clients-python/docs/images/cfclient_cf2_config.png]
CF2 config


Once the settings has been made press the write button to save them permanently in the Crazyflie 2.X EEPROM.  Then restart the Crazyflie and connect to the new address.

### Logging

The Crazyflie logging framework allows to log the state of Crazyflie
variables in real-time. This subsystem is used by the client to show
information like pose or battery level.

The list of log variable can be seen in the \"log TOC\" tab in the
client.

Variables are logged in block: one log block is a list of variable that
are logged at the same time. You can setup custom log blocks that can be
plotted in the plotter and saved to file in the log block tab.

To setup a new log block click on the menu \"settings/logging
configuration\", You then see the following toolbox:

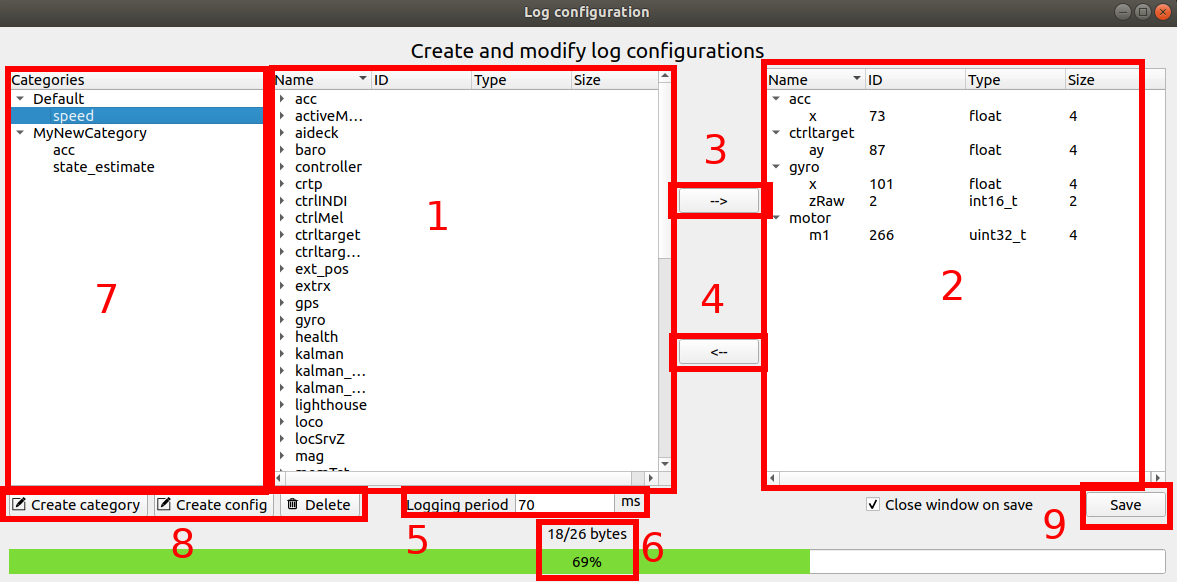
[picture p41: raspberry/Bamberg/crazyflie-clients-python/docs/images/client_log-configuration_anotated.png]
cfclient logging configuration


1.  List of log variable in the Crazyflie
2.  Log variables in the current log block
3.  Add the selected Crazyflie log variable in the log block
4.  Remove the selected log block variable from the log block
5.  Period at which the variables are sampled and the block is send by
    the Crazyflie to the client. The minimum possible period is 10ms
    (100Hz) and it can be set by step of 10ms up to 2550ms.
6.  Bytes used by the variables in the log block.
7.  File-tree structure where you can sort the log-blocks into categories.
8.  Create/delete a category or a log-configuration. This can also
    be done by right-clicking anywhere in the category-tree.
9.  Save log block configuration

### Flight settings

By using the settings on the [Flight control tab](./flightcontrol_tab.md) you can set
things such as the max roll/pitch and thrust.

### Input devices

In order to control the Crazyflie you are connected to you will need
some input-device. Normally this would be a gamepad, but any
input-device with at least 4 analog axis will do. Here\'s
[a list](/docs/userguides/inputdevices.md) of some input-devices
that are used.

In order to make sense of the input from the device a mapping has to be
supplied. This mapping will convert raw axis values on the input-device
to useful values like roll/pitch/yaw/thrust. There\'s a few default
mappings shipped with the client, but it\'s easy to create your own.

### Creating new mappings

The software comes bundled with mappings for Xbox and PS3/4 controllers,
but if you have another input-device then it\'s quick to create your own
configuration. Go to the menu *Input device -\> Configure device
mapping*.

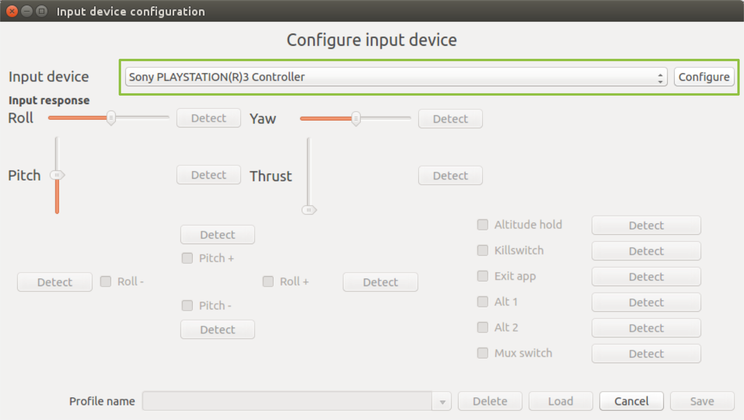
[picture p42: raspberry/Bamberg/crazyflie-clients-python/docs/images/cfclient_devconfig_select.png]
cfclient configure device
{:align-center
width="700"}

Select the device you would like to configure and press *Configure*.

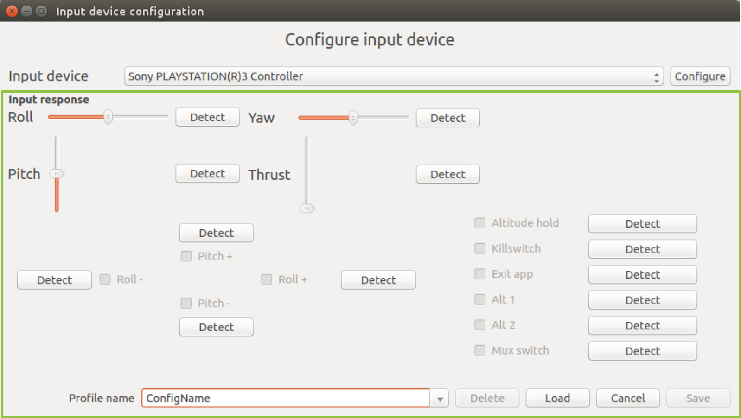
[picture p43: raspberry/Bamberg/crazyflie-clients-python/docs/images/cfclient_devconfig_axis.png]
cfclient configure device axis
{:align-center
width="700"}

For each functionality that can be mapped there\'s a *Detect* button, by
pressing it the following dialog will appear.

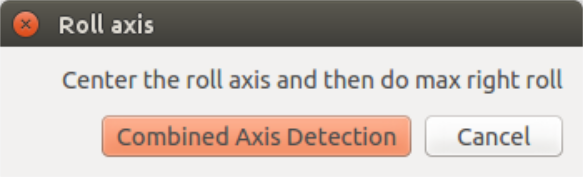
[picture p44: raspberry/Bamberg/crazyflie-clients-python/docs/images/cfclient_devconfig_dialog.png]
cfclient configure device detect
{:align-center
width="300"}

Follow the instructions to detect the axis or button that you would like
to map to the functionality. If you would like to map the functionality
to two axis (like right/left shoulder-button) then select *Combined axis
detection* and follow the instructions.

Go though all the functionality you would like to map by pressing the
*Detect* button for each. To be able to save the mapping you will at
least have to map roll, pitch, yaw and thrust.

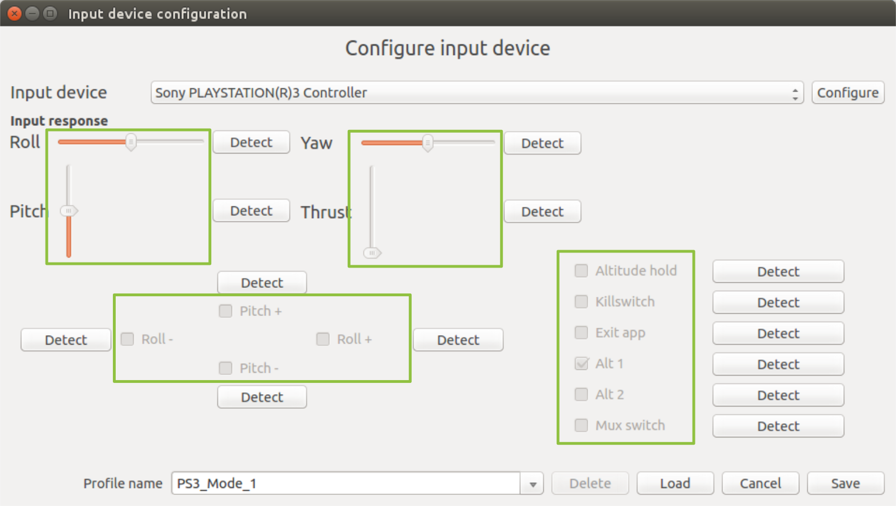
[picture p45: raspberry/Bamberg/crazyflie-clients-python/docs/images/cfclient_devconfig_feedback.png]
cfclient configure device feedback
{:align-center
width="700"}

Once you have mapped functionality you will be able to see the feedback
directly in the configuration dialog (when you\'re not detecting a
button). Make sure to check that the response is what you intended. When
you are finished with the mapping then enter the map name and press
save.

If you would like to start from a previous configuration and change it
(either to update or to create a new one) then select the appropriate
mapping in the drop-down and press *Load*. Once you have made the
changes you would like to do then either press *Save* without changing
the name to update the mapping or enter a new name and press *Save* to
create a new one.

### Selecting device

The current input device and mapping can be selected from the *Input
device* menu.

The *Input device* menu contains a number of different \"modes\" that
can be used for controlling a Crazyflie. Currently there\'s thee to
choose from. The alternatives will only be enabled if there\'s enough
input devices connected to use them.

-   *Normal:* Just like it says this is the normal mode using only one
    controller to control a Crazyflie
-   *Teacher (RP):* This mode requires two input-devices, where one will
    be configured for roll and pitch and the other one for the rest of
    the functionality. By using the *Mux switch* functionality (mapped
    in the configuration) the second controller can take over roll and
    pitch as well
-   *Teacher (RPYT):* This mode requires two input-devices, where one
    will be configured for roll, pitch yaw and thrust, and the other one
    for the rest of the functionality. By using the *Mux switch*
    functionality (mapped in the configuration) the second controller
    can take over roll, pitch, yaw and thrust as well

For normal usage just enter the *Normal* menu, select the device you
would like to use and the correct mapping. As a device is selected the
list of mappings are enabled.

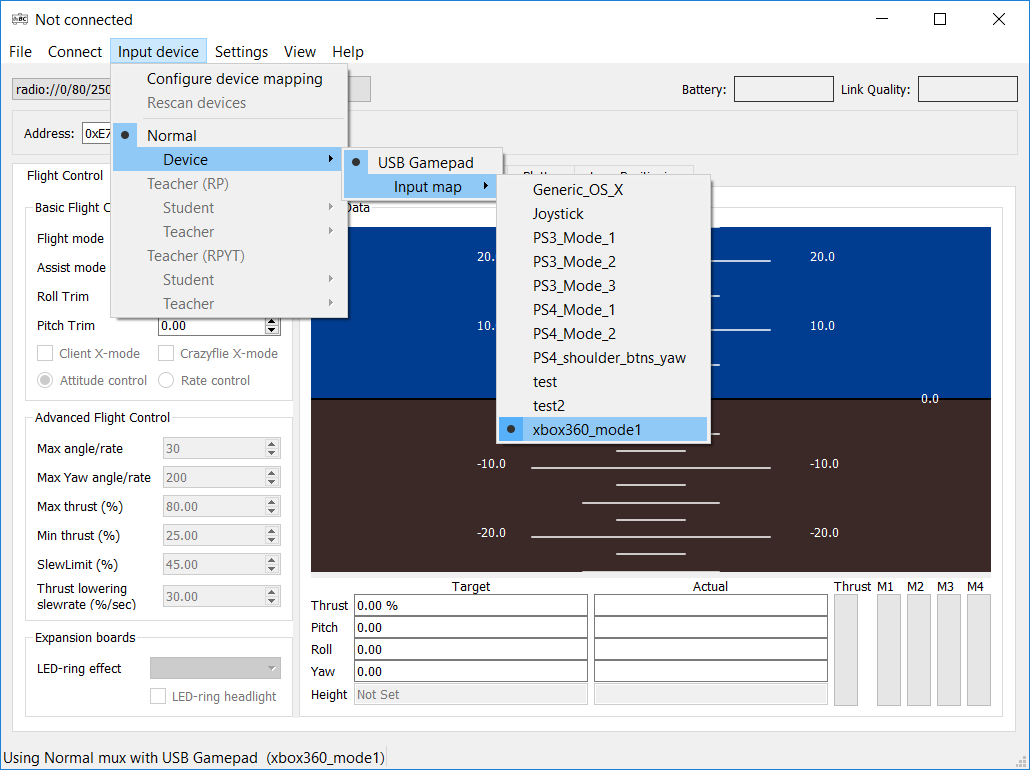
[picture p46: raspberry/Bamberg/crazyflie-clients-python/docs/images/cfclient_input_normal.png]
cfclient devices normal
{:align-center
width="700"}

If more than one input device is connected then it\'s possible to switch
to one of the teacher modes.

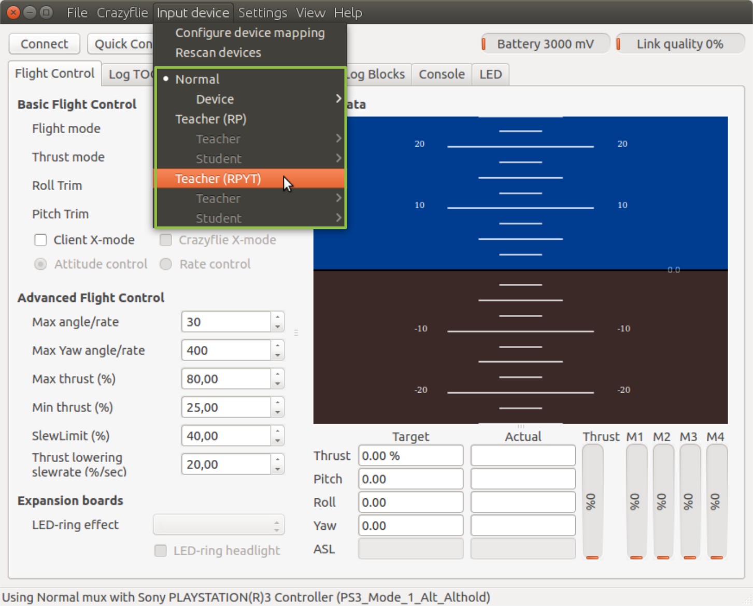
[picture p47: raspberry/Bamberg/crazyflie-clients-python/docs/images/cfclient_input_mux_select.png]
cfclient devices mux select
{:align-center
width="700"}

First select the device that should be used for the teacher and then
it\'s mapping.

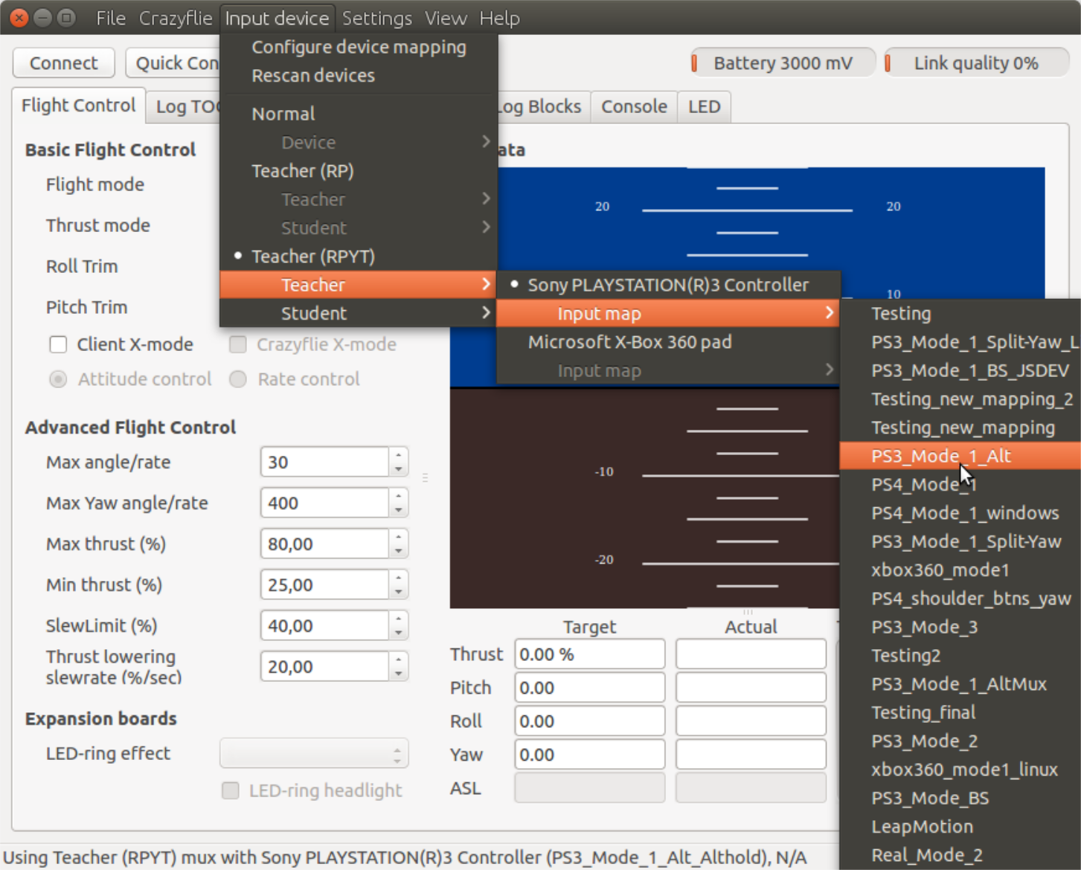
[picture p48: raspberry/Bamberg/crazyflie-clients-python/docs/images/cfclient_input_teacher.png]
cfclient input teacher
{:align-center
width="700"}

Then select the device that should be used for the student and then
it\'s mapping.

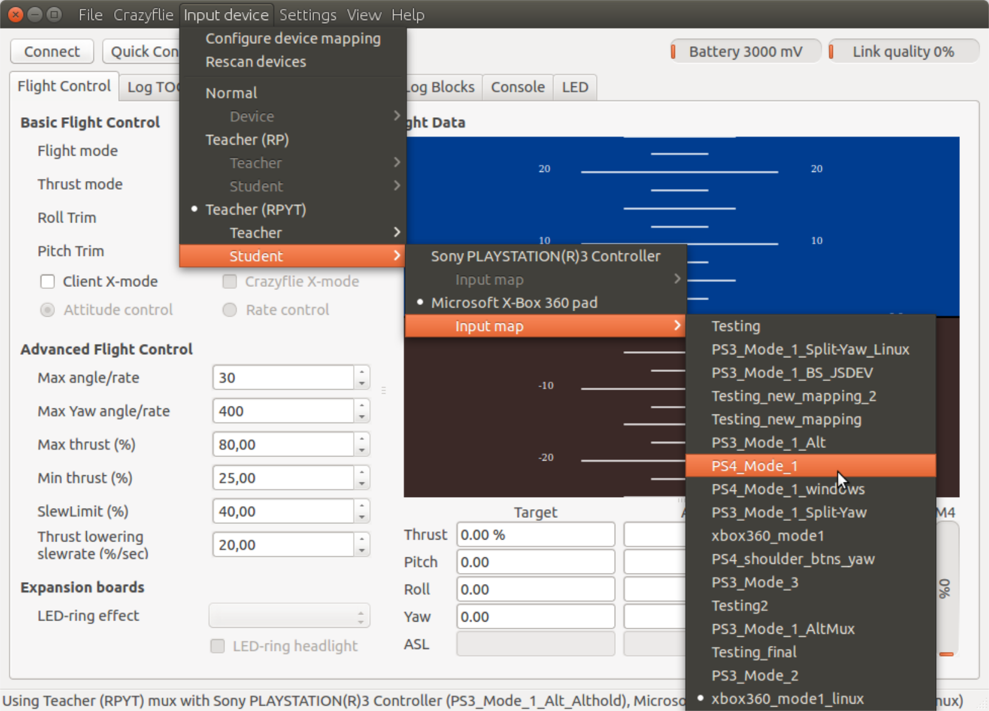
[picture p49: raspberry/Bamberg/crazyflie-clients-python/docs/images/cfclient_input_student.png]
cfclient input student
{:align-center
width="700"}

Once this is done you will be able to see the open devices and
configurations at the bottom of the user interface.

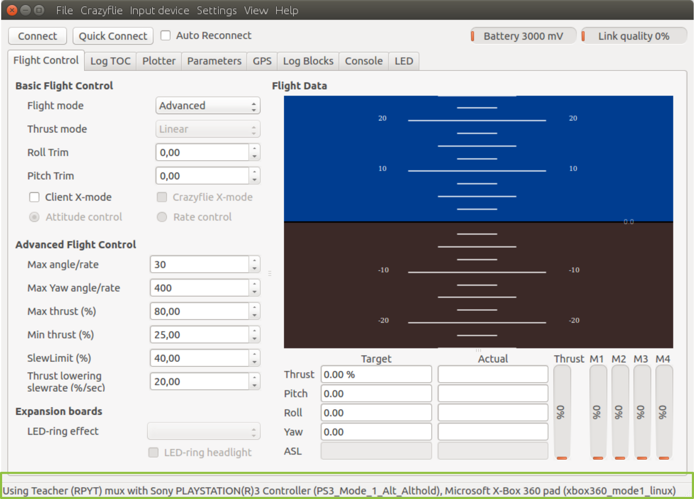
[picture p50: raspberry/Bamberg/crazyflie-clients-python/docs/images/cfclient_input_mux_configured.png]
cfclient input mux configured
{:align-center
width="700"}

---

## ZMQ backends

The UI is normally used to get/set parameters, view logged data and send
control commands to the Crazyflie. Aside from this there\'s also the
possibility to connect via ZMQ to the client and control several things:

-   [Parameters](/docs/functional-areas/cfclient_zmq.md#parameters):
    Get/set parameters by name
-   [LED-ring memory](/docs/functional-areas/cfclient_zmq.md#led-ring):
    Write LED ring memory
-   [Input-device](/docs/functional-areas/cfclient_zmq.md#input-device):
    Act as an input device

The benefit of using this approach instead of the stand-alone ZMQ
server is that you will not have to
take care of everything, just the parts you are interested in for the
moment.

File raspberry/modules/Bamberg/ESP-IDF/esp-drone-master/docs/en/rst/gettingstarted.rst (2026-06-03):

================
Get Started 
================

:link_to_translation:`zh_CN:[中文]`

ESP-Drone Overview
======================

ESP-Drone is an ESP32/ESP32-S2/ESP32-S3 based flying development board provided by Espressif. ESP-Drone is equipped with Wi-Fi key features, which allows this drone to be connected to and controlled by an APP or a gamepad over a Wi-Fi network. This drone comes with simple-structured hardware, clear codes, and supports functional extension. Therefore, ESP-Drone can be used in STEAM education. Part of the codes is from Crazyflie open source project under GPL3.0
license.

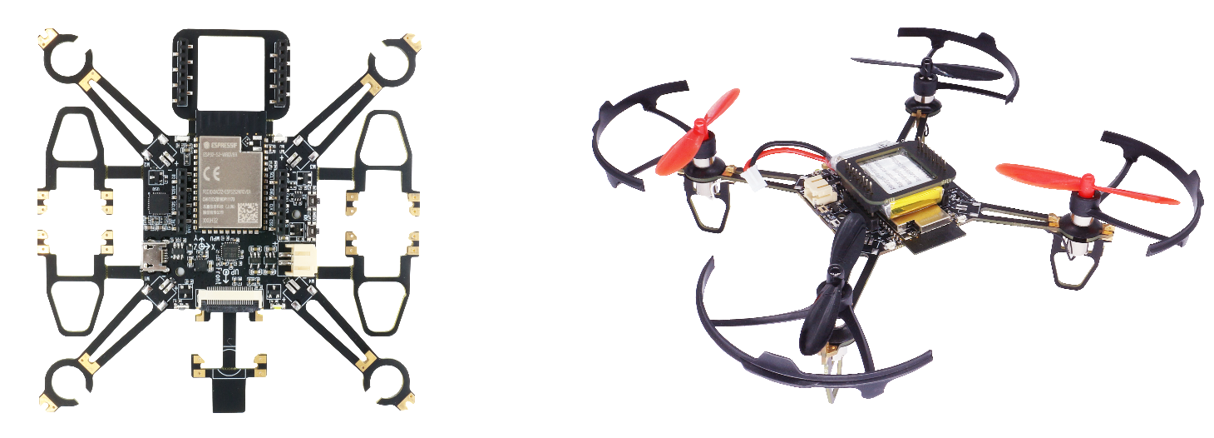
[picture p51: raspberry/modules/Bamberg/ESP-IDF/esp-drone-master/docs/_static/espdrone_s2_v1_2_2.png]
ESP-Drone

   
   ESP-Drone

Main Features
----------------

ESP-Drone has the following features:

- Stabilize mode: keep the drone stable to achieve smooth flight.
- Height-hold mode: control thrust output to keep the drone flying at a fixed height.
- Position-hold mode: keep the drone flying at a fixed position.
- PC debugging: use cfclient for static/dynamic debugging.
- Controlled by APP: easily controlled over Wi-Fi by your mobile APP.
- Controlled by gamepad: easily controlled via the gamepad by cfclient.

Main Components
----------------

ESP-Drone 2.0 consists of a main board and several extension boards:

-  **Main board**: integrates an ESP32-S2 module, necessary sensors for basic flight, and provides hardware extension interfaces.
-  **Extension boards**: integrate extension sensors via hardware extension interfaces of the main board, to implement advanced flight.  

.. list-table:: 
   :widths: 4 20 15 15 10 10
   :header-rows: 1

   * - No.
     - Modules
     - Main Components
     - Function
     - Interfaces
     - Mount Location
   * - 1
     - Main board - **ESP32-S2**
     - ESP32-S2-WROVER + MPU6050
     - Basic flight
     - I2C, SPI, GPIO, extension interfaces
     - 
   * - 2
     - Extension board - **Position-hold module**
     - PMW3901 + VL53L1X
     - Indoor position-hold flight
     - SPI + I2C
     - Mount at bottom, facing to the ground.
   * - 3
     - Extension board - **Pressure module**
     - MS5611 pressure module
     - Height-hold flight
     - I2C or MPU6050 slave
     - Mount at the top or at the bottom
   * - 4
     - Extension board - **Compass module**
     - HMC5883 compass
     - Advanced flight mode, such as head-free mode
     - I2C or MPU6050 slave
     - Mount at the top or at the bottom

For more information, please refer to `Hardware Reference <./hardware.rst>`__.

ESP-IDF Overview
================

ESP-IDF is the IoT Development Framework provided by Espressif for ESP32/ESP32-S2/ESP32-S3.

- ESP-IDF is a collection of libraries and header files that provides the core software components that are required to build any software projects on ESP32/ESP32-S2.

- ESP-IDF also provides tools and utilities that are required for typical developer and production use cases, like build, flash, debug and measure. 

For more information, please check `ESP-IDF
Programming Guide <https://docs.espressif.com/projects/esp-idf/en/release-v5.0/esp32s2/get-started/index.html>`__.

Crazyflie Overview
=======================

Crazyflie is a Bitcraze open-source quadcopter, with the following features:

- Support various sensor combinations for advanced flight modes, such as Height-hold mode and Position-hold mode.
- Based on FreeRTOS, which allows users to break down complex drone systems into multiple software tasks with various priorities.
- Customized full-featured cfclient and CRTP communication protocol, for debug, measurement, and control purposes.

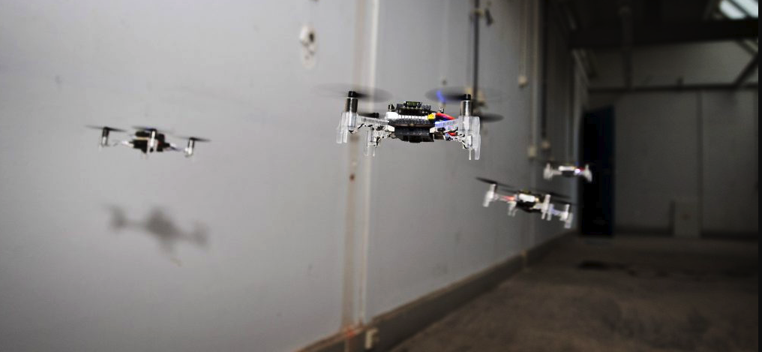
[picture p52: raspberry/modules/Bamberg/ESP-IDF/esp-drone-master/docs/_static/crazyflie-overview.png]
crazyflie-overview

   
   `A swarm of drones exploring the environment, avoiding obstacles
   and each other. (Guus Schoonewille, TU Delft) <https://img-blog.csdnimg.cn/20191030202634944.jpg?x-oss-process=image/watermark,type_ZmFuZ3poZW5naGVpdGk,shadow_10,text_aHR0cHM6Ly9ibG9nLmNzZG4ubmV0L3FxXzIwNTE1NDYx,size_16,color_FFFFFF,t_70>`__

For more information, see `Crazyflie <https://www.bitcraze.io/>`__.

Preparations
================

Assemble Hardware
--------------------

Please follow the steps below to assemble ESP32-S2-Drone V1.2.

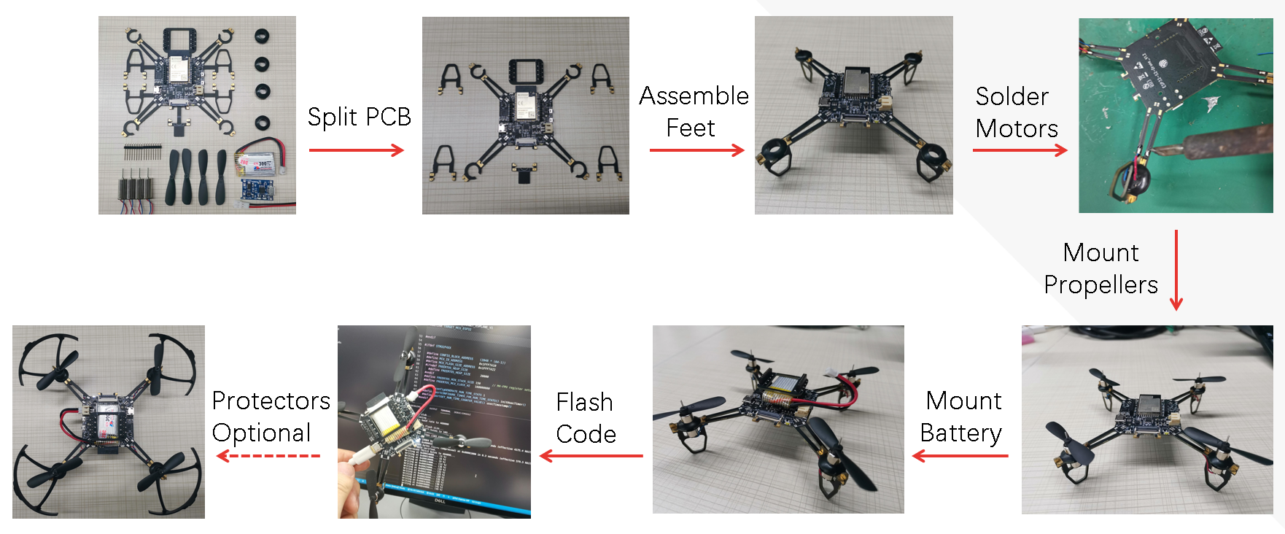
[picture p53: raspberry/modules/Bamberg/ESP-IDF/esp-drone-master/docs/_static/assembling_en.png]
ESP32-S2-Drone V1.2 Assemble Flow

   
   ESP32-S2-Drone V1.2 Assemble Flow

Hardware overview and pin allocation are available at: `Hardware Reference <./hardware.rst>`__.

Download and Install ESP-Drone APP
----------------------------------------
ESP-Drone APP is available for Android and iOS.

For Android, please scan the QR below to download ESP-Drone APP.

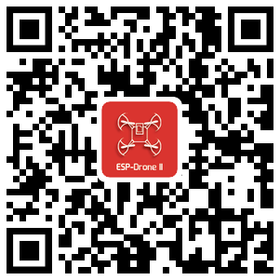
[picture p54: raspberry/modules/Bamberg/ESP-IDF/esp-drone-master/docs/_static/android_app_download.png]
Android APP QR


For iOS, please search and download the ESP-Drone APP in App Store.

iOS APP source code:
`ESP-Drone-iOS <https://github.com/EspressifApps/ESP-Drone-iOS>`__

Android APP source code:
`ESP-Drone-Android <https://github.com/EspressifApps/ESP-Drone-Android>`__

Install cfclient
--------------------

This step is optional, only for advanced debugging.

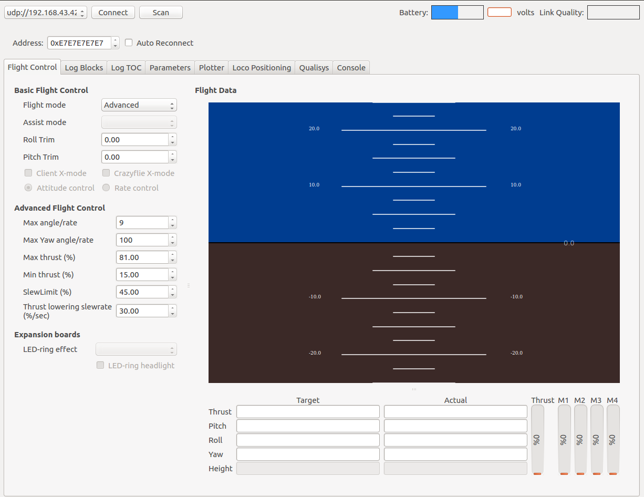
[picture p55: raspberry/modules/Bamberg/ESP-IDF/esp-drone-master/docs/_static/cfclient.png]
cfclient Interface


   cfclient Interface

**1. Install cfclient**

1.1 Download the source code

.. code:: text

   git clone https://github.com/qljz1993/crazyflie-clients-python.git

1.2 Check into the directory

.. code:: text

   cd crazyflie-clients-python

1.3 Install cfclient

.. code:: text

   pip3 install -e .

1.4 Start cfclient

.. code:: text

   cfclient

**2. Configure the controllers**

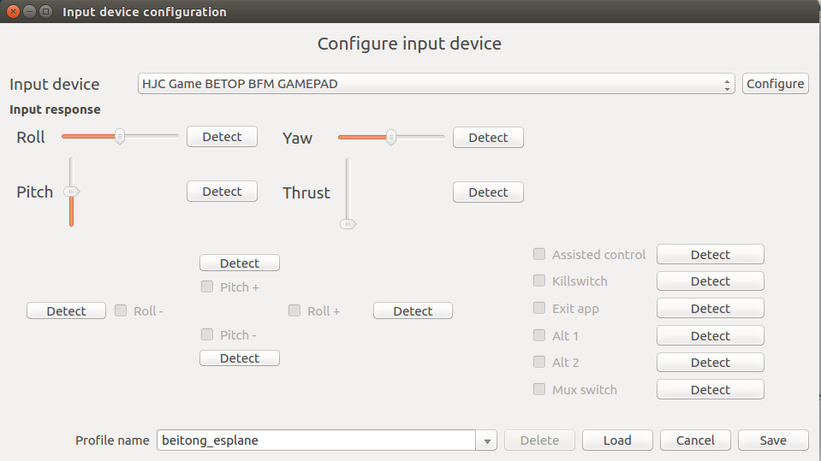
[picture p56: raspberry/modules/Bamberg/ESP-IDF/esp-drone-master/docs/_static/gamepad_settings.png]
Controller Configuration


   Controller Configuration

2.1 Configure the four main dimensions of controls: ``Roll, Pitch, Yaw, Thrust``.

2.2 Configure button ``Assisted control`` for flight mode switching.

ESP-Drone APP Guide
=====================

Establish Wi-Fi connection
---------------------------
* Scan Wi-Fi AP on your mobile. ESP-Drone device works as a Wi-Fi AP with the following SSID:  

::

   SSID: ESP-DRONE_XXXX (XXXX is configured based on MAC) PASSWORD: 12345678

* Click this AP, connect your mobile to this AP.

Now a Wi-Fi connection is established between your mobile and your drone.

Customize settings
---------------------------
In this step, you can customize the flight settings according to your application scenarios, or use the default configuration below.

::

   ```
   Default configuration:

   Flight control settings 
       1. Mode: Mode2
       2. Deadzone: 0.2
       3. Roll trim: 0.0
       4. Pitch trim: 0.0
       5. Advanced flight control: true
       6. Advanced flight control preferences 
           1. max roll/pitch angle: 15
           2. max yaw angle: 90
           3. max thrust: 90
           4. min thrust: 25
           5. X-Mode: true
   Controller settings 
       7. use full travel for thrust: false
       8. virtual joystick size: 100
   App settings
       9. Screen rotation lock: true
       10. full screen mode:true
       11. show console: true   
   ```

Flight Control
---------------------

- Click “Connect” button/icon at your APP. When the connection is established successfully between your drone and APP, the LED on the drone blinks GREEN.
- Slide “Thrust” slightly to take off the drone.
- Control the flight by moving your fingers on the APP.

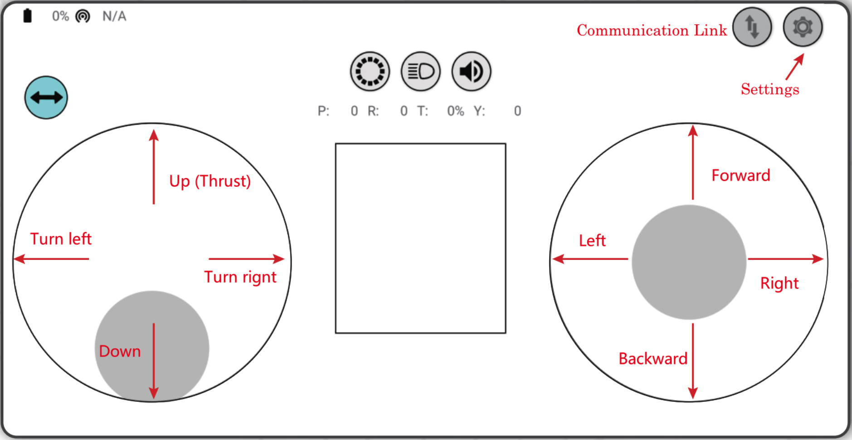
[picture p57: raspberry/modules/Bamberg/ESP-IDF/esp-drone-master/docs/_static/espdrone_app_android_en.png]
Android APP Interface


   Android APP Interface

PC cfclient Guide
======================

Cfclient is the PC client for ``Crazeflie`` source project, which has fully implemented the functions defined in ``CRTP`` and makes the drone debugging faster. ESP-Drone customizes this cfclient to meet functional design needs.

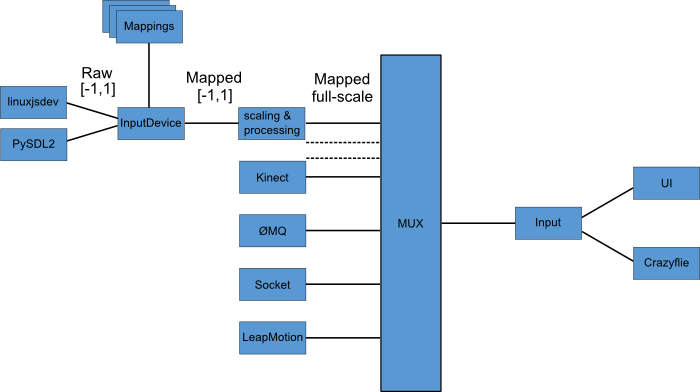
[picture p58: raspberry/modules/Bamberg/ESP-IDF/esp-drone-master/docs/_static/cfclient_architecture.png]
cfclient architecture


   Cfclient Architecture

cfclient console interface

   Cfclient Console Interface

In this project, we have configuration files and cache files. JSON file is used to store configuration information. For more information about the configuration, please refer to `User
Configuration File <https://www.bitcraze.io/documentation/repository/crazyflie-clients-python/master/development/dev_info_client/>`__.

Flight Settings
--------------------

Basic Flight Control
~~~~~~~~~~~~~~~~~~~~~~

1. Flight mode: normal and advanced modes

   - Normal mode: for beginners.
   - Advanced mode: unlock the maximum angle and the maximum thrust.

2. Assisted mode

   - Altitude-hold mode: maintain flight altitude. To implement this mode, a barometric pressure sensor is needed.
   - Position-hold mode: maintain current flight position. To implement this mode, an optical flow sensor and a Time of Flight (TOF) sensor are needed.
   - Height-hold mode: keep flight height. Note: to apply this mode, the drone should fly at 40 cm or higher over the ground, and a TOF is needed.
   - Hover mode: stay and hover at 40 cm or higher over the take-off point. To implement this mode, a optical flow sensor and a TOF are needed.

3. Trim

   - Roll Trim: trim the rotation around a horizontal axis going through the drone from back to front. This rotation literally rolls the drone and moves it left and right. Roll trim is used to compensate for the level installation deviation of sensors.
   - Pitch Trim: trim the rotation around a horizontal axis going through the drone from left to right. This rotation tilts the drone and moves it forwards or backwards. Pitch trim is used to compensate for the level installation deviation of sensors.

Note that in assisted mode, the thrust controller works as a height controller.

Advanced Flight Control
~~~~~~~~~~~~~~~~~~~~~~~~

1. Max angle: set the maximum pitch and roll rotation: roll/pitch.
2. Max yaw rate: set the allowed yaw: ``yaw``.
3. Max thrust: set the maximum thrust.
4. Min thrust: set the minimum thrust.
5. Slew limit: prevent sudden drop of thrust. When the thrust drops below this limit, the rates below ``Slew rate`` will not be allowed.
6. Slew rate: this is the maximum rate when the thrust is below ``slew limit``.

Configure Input Device
~~~~~~~~~~~~~~~~~~~~~~~~~~~~~

Follow the prompts, route the controllers to each channel.

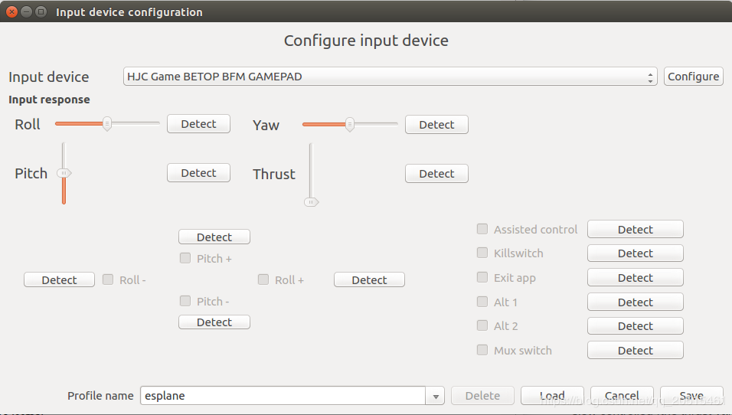
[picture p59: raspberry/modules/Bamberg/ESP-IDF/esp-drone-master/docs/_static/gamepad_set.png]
cfclient input device configuration


   Cfclient Input Device Configuration

Flight Data
~~~~~~~~~~~~~~~~

On the tab “Flight Control” of cfclient, you can check the drone status. The detailed information is shown at the bottom right, including:

1. Target: target angle
2. Actual: measured angle
3. Thrust: current thrust value
4. M1/M2/M3/M4: actual output of motors

Tune Online Parameters
--------------------------

**Tune PID parameters online**

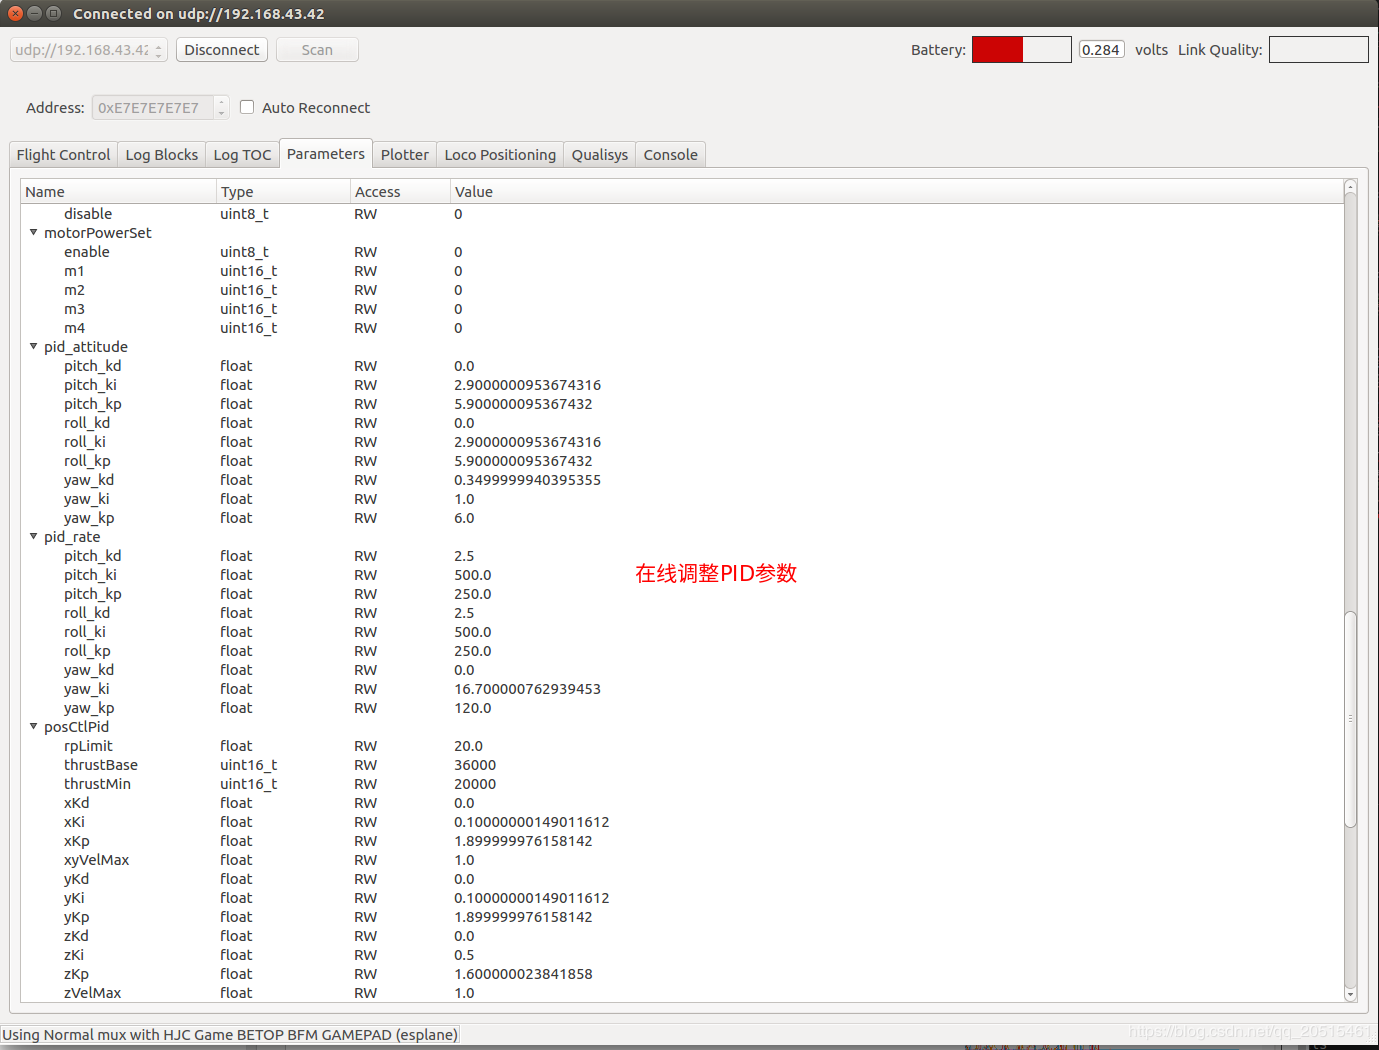
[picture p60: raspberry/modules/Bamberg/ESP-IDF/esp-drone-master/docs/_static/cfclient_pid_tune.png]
PID parameters tunning

   
   Cfclient PID Parameters Tunning

**Note**

1. The modified parameters take effect in real time, which avoids frequent flash of firmware.
2. You can define in your code which parameters can be modified by PC in real time.
3. Note that modifying parameters online is only for debugging purpose. The modified parameters will not be saved at power down.

Monitor Flight Data
-----------------------

Configure the parameters to monitor at Tab Log configuration and Tab Log Blocks:

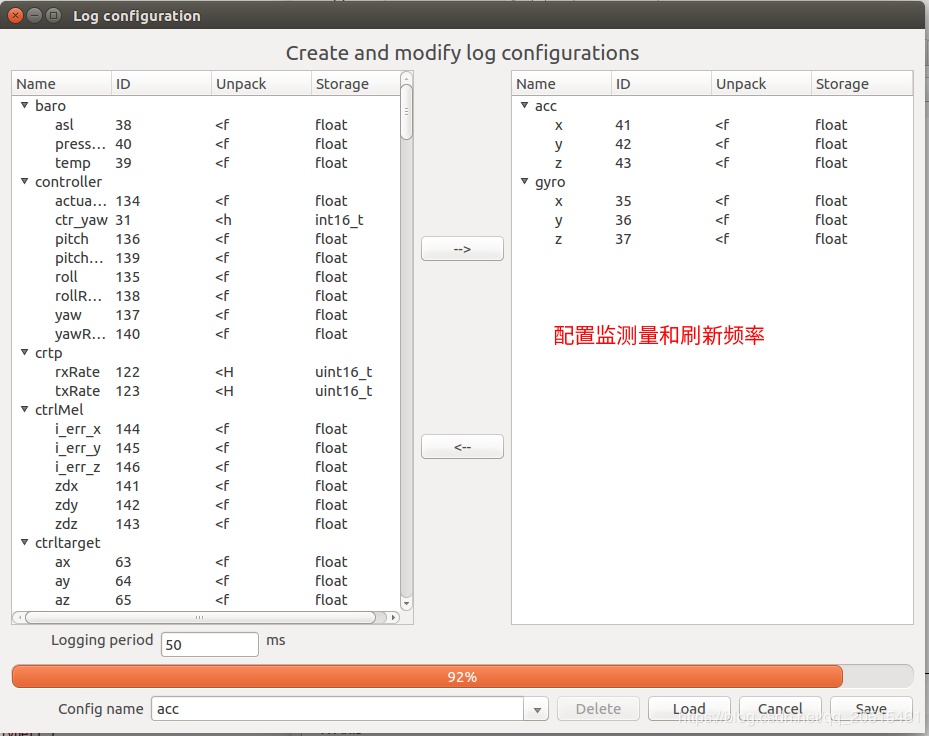
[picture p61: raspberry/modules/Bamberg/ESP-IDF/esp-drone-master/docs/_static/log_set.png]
Log configuration

   
   Log Configuration

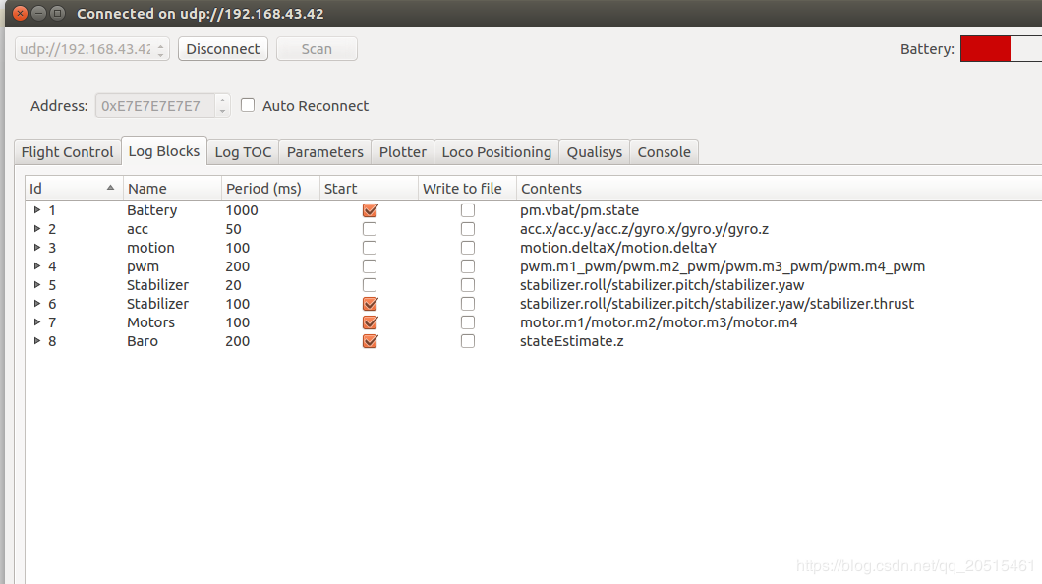
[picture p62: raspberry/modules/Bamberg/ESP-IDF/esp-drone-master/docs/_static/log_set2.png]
Log Blocks

   
   Log Blocks

Configure real-time waveform drawing at Tab Plotter, to monitor gyro accelerometer data.

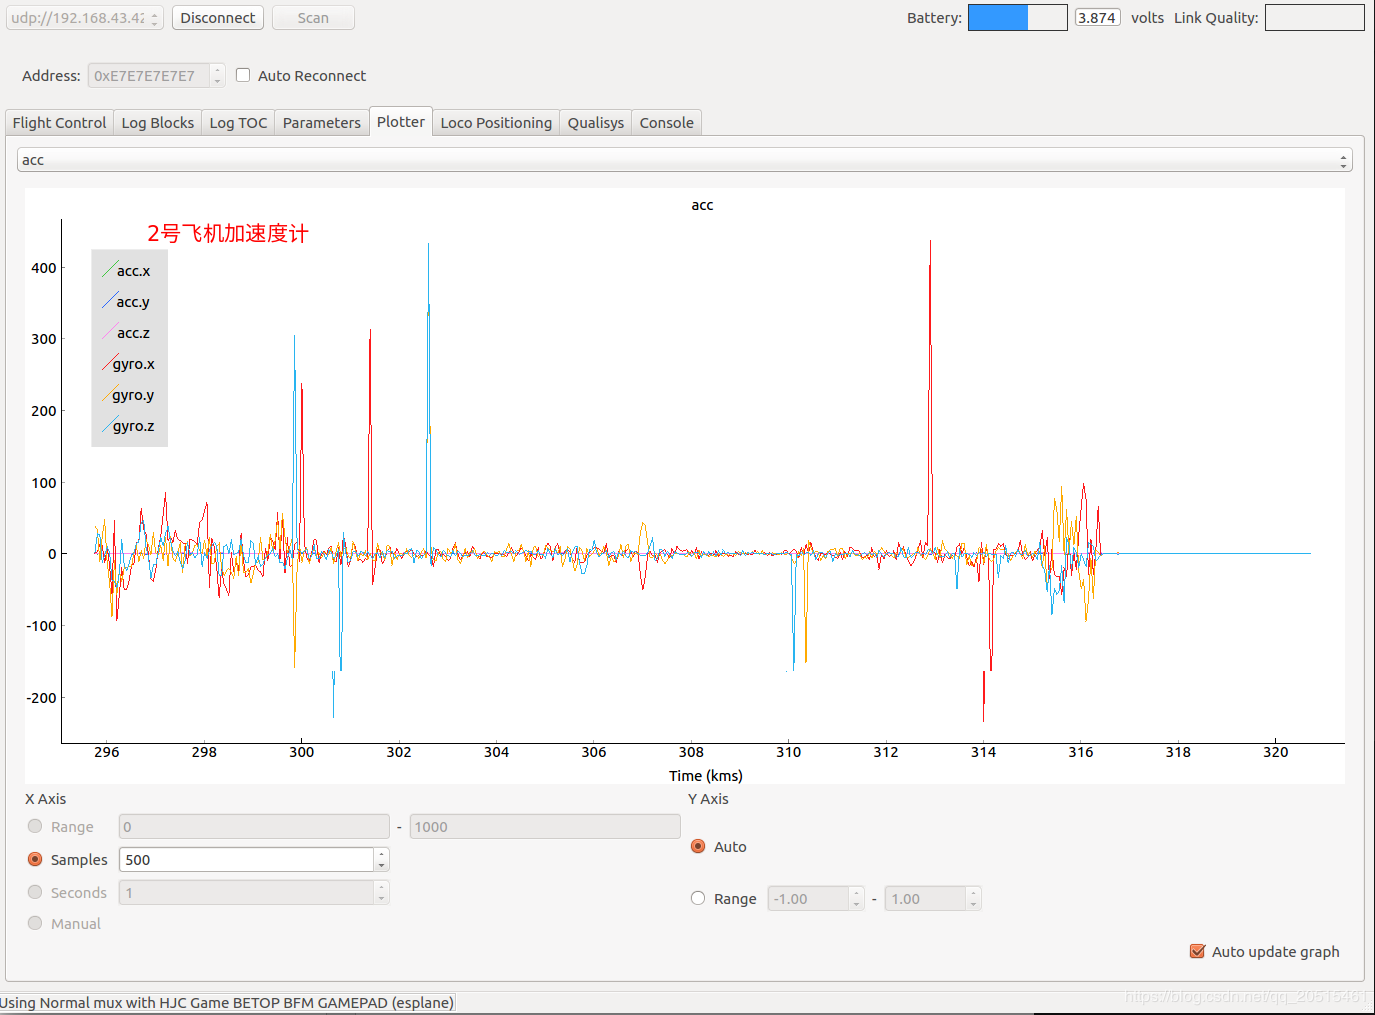
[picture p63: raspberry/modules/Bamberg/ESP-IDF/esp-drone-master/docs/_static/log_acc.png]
accelerometer logging


   Accelerometer Logging

Propeller Direction
=======================

- Install A and B propellers according to the figure below.
- During the power-on self-test, check if the propellers spin properly.

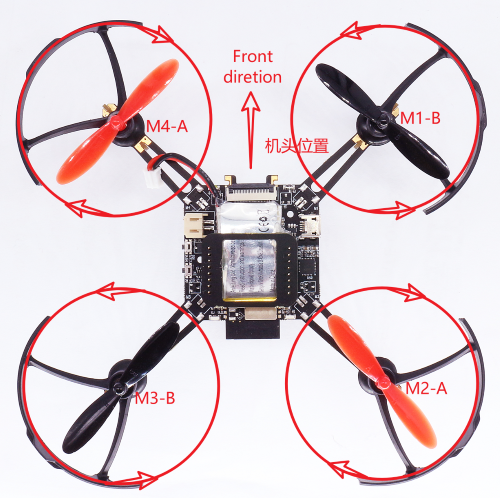
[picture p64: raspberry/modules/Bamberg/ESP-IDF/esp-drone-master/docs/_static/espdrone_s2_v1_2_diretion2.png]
Propeller check


   Propeller Check

Preflight Check
================

- Place the drone with its head on the front, and its tail (i.e. the antenna part) at the back.
- Place the drone on a level surface and power it up when the drone stays still.
- Check on the cfclient if the drone is placed level.
- After the communication is established, check if the LED at the drone tail blinks GREEN fast.
- Check if the LED on the drone head blinks RED, which indicates battery LOW.
- Slide forward the Trust controller slightly at the left side of your APP (i.e. the commands controlled by your left finger), to check if the drone can respond the command quickly.
- Move your finger at the right command area of the APP (i.e. the commands controlled by your right finger), to check if the direction control works well.
- Go fly and have fun!

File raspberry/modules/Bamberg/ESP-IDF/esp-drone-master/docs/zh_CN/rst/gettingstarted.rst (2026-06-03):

========
快速入门
========

:link_to_translation:`en:[English]`

项目简介
========

ESP-Drone 是基于乐鑫 ESP32/ESP32-S2/ESP32-S3 开发的小型无人机解决方案，可使用手机 APP 或游戏手柄通过 Wi-Fi
网络进行连接和控制。该方案硬件结构简单，代码架构清晰，支持功能扩展，可用于
STEAM 教育等领域。项目部分代码来自 Crazyflie 开源工程，继承 GPL3.0
开源协议。

ESP-Drone 无人机
   
   ESP-Drone 无人机

主要特性
---------

ESP-Drone 具备以下特性：

-  支持自稳定模式 (Stabilize mode)：自动控制机身水平，保持平稳飞行。
-  支持定高模式 (Height-hold mode)：自动控制油门输出，保持固定高度。
-  支持定点模式 (Position-hold mode)：自动控制机身角度，保持固定空间位置。
-  支持 PC 上位机调试：使用 cfclient 上位机进行静态/动态调试。
-  支持 APP 控制：使用手机 APP 通过 Wi-Fi 轻松控制。
-  支持游戏手柄 (gamepad) 控制：通过 cfclient 使用游戏手柄轻松控制。

主要组件
----------------

ESP-Drone 2.0 使用模块化的设计思路，由主控板和扩展板组成。

-  **主控制板**：搭载 ESP32-S2 模组和支持基础飞行的必要传感器，并提供硬件扩展接口。
-  **扩展板**：搭载扩展传感器，可对接主控制板的硬件扩展接口，支持高级飞行功能。

==== ========================= ========================= ================== ========================== ==============
序号 模块名                    主要元器件                功能               接口                       安装位置
==== ========================= ========================= ================== ========================== ==============
1    主控制板 - **ESP32-S2**   ESP32-S2-WROVER + MPU6050 基础飞行           提供 I2C SPI GPIO 扩展接口
2    扩展板 - **定点模块**     PMW3901 + VL53L1X         室内定点飞行       SPI + I2C                  底部，面向地面
3    扩展板 - **气压定高模块** MS5611 气压               气压定高           I2C 或 MPU6050 从机        顶部或底部
4    扩展板 - **指南针模块**   HMC5883 罗盘              无头模式等高级模式 I2C 或 MPU6050 从机        顶部或底部
==== ========================= ========================= ================== ========================== ==============

详情可查阅：`硬件参考 <./hardware.rst>`__。

ESP-IDF 简介
================

ESP-IDF 是乐鑫为 ESP32/ESP32-S2/ESP32-S3 提供的物联网开发框架。

-  ESP-IDF 包含一系列库及头文件，提供了基于 ESP32/ESP32-S2/ESP32-S3 构建软件项目所需的核心组件。
-  ESP-IDF 还提供了开发和量产过程中最常用的工具及功能，例如：构建、烧录、调试和测量等。

详情可查阅：`ESP-IDF 编程指南 <https://docs.espressif.com/projects/esp-idf/en/release-v5.0/esp32s2/get-started/index.html>`__。

Crazyflie 简介
================

Crazyflie 是来自 Bitcraze 开源工程的四旋翼飞行器，具备以下特性：

-  支持多种传感器组合，可以轻松实现定高模式、定点模式等高级飞行模式。
-  基于 FreeRTOS 编写，将复杂的无人机系统，分解成多个具有不同优先级的软件任务。
-  设计了功能完备的 cfclient 上位机和 CRTP 通信协议，便于实现调试、测量和控制。

crazyflie-overview

   多架无人机同时探索周围环境，灵活避开障碍物，同时避开其它无人机。\ `A
   swarm of drones exploring the environment, avoiding obstacles and
   each other. (Guus Schoonewille, TU
   Delft) <https://img-blog.csdnimg.cn/20191030202634944.jpg?x-oss-process=image/watermark,type_ZmFuZ3poZW5naGVpdGk,shadow_10,text_aHR0cHM6Ly9ibG9nLmNzZG4ubmV0L3FxXzIwNTE1NDYx,size_16,color_FFFFFF,t_70>`__

详情可查阅 `Crazyflie 官网 <https://www.bitcraze.io/>`__。

准备工作
================

硬件组装
----------

请按照下述步骤组装 ESP32-S2-Drone V1.2：

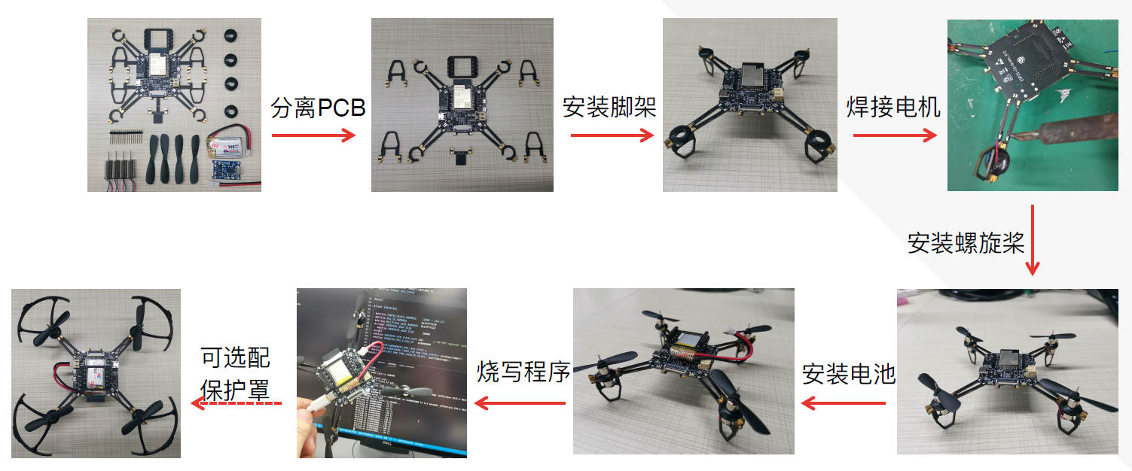
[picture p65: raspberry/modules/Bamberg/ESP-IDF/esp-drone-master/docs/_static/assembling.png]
ESP32-S2-Drone V1.2 组装流程

   
   ESP32-S2-Drone V1.2 组装流程

硬件介绍和管脚资源分配可查阅：`硬件参考 <./hardware.rst>`__。

安装 ESP-Drone APP
--------------------

ESP-Drone APP 同时支持 Android 系统和 iOS 系统。

**扫描下方二维码，下载 Android APP：**

Android APP 扫码下载

**下载 iOS APP：**

在 App Store 中搜索 ESP-Drone，点击下载并安装。

**iOS APP 源代码**：`ESP-Drone-iOS <https://github.com/EspressifApps/ESP-Drone-iOS>`__

**Android APP 源代码**：`ESP-Drone-Android <https://github.com/EspressifApps/ESP-Drone-Android>`__

安装 cfclient
--------------------

安装 cfclient 为可选步骤，用于实现高级调试，非必须使用。

cfclient 上位机界面

   cfclient 上位机界面

**1. 安装 cfclient**

1.1 下载源代码

.. code:: text

   git clone https://github.com/qljz1993/crazyflie-clients-python.git

1.2 进入下载目录

.. code:: text

   cd crazyflie-clients-python

1.3 安装 cfclient 客户端

.. code:: text

   pip3 install -e .

1.4 启动客户端

.. code:: text

   cfclient

**2. 配置遥控器**

游戏手柄配置

   遥控器配置

2.1 配置 4 个控制轴：``Roll 、Pitch、Yaw、Thrust``。

2.2 配置一个按键为 ``Assisted control``，用于飞行模式切换。

手机 APP 使用指南
========================

Wi-Fi 连接
---------------------------
* 手机扫描 Wi-Fi AP。ESP-Drone 设备用作 AP，其 SSID 及密码如下：

::

   SSID：ESP-DRONE_XXXX（XXXX 根据 MAC 设置）PASSWORD：12345678

* 点击该 AP，手机与 ESP-Drone 设备建立 Wi-Fi 连接。

个性化设置
-----------

在该步骤中，您可以按照具体的应用场景进行个性化配置，或使用默认配置。

::

   ```
   默认配置：

   Flight control settings 
       1. Mode: Mode2
       2. Deadzone: 0.2
       3. Roll trim: 0.0
       4. Pitch trim: 0.0
       5. Advanced flight control : true
       6. Advanced flight control preferences 
           1. max roll/pitch angle: 15
           2. max yaw angle: 90
           3. max thrust: 90
           4. min thrust: 25
           5. X-Mode: true
   Controller settings 
       1. use full travel for thrust: false
       2. virtual joystick size: 100
   App settings
       1. Screen rotation lock: true
       2. full screen mode:true
       3. show console: true   
   ```

控制飞行
--------

-  打开 APP，点击 `Connect` 按钮，连接小飞机。连接成功，小飞机绿灯闪烁。
-  轻推油门，小飞机起飞。
-  在 APP 上滑动，控制小飞机方向。

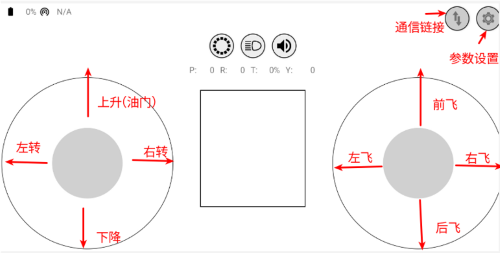
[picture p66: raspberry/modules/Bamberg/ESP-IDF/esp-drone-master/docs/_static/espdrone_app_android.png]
Android APP 用户界面


   Android APP 用户界面

PC cfclient 使用指南
========================

cfclient 是 ``Crazeflie`` 源工程的上位机，完全实现了 ``CRTP``
协议中定义的功能，可以加快飞机的调试过程。ESP-Drone
项目对该上位机进行裁剪和调整，满足功能设计需求。

cfclient 架构

   cfclient 架构

cfclient 控制台界面

   cfclient 控制台界面

项目中有很多相关的文件，例如配置文件和缓存文件，其中 JSON
文件用来存储配置信息。关于配置信息中内容的解读，可参考：`User
Configuration
File <https://www.bitcraze.io/documentation/repository/crazyflie-clients-python/master/development/dev_info_client/>`__。

飞行设置
----------

基本飞行设置 (Basic Flight Control)
~~~~~~~~~~~~~~~~~~~~~~~~~~~~~~~~~~~~~

1. 飞行模式 (Flight mode)：基本模式和高级模式

   -  基本模式 (Normal mode)：初学者使用。
   -  高级模式 (Advanced mode)：设置解锁最大角度，设置最大油门。

2. 自动模式 (Assisted mode)

   -  定海拔模式 (Altitude-hold mode)：保持飞行海拔，需要气压计支持。
   -  定点模式 (Position-hold mode)：保持当前位置，需要光流和 TOF 支持。
   -  定高模式 (Height-hold mode)：保持相对高度，触发时保持高于地面 40
      cm，需要 TOF 支持。
   -  悬停模式 (Hover mode)：触发时保持高于地面 40
      cm，并悬停在起飞点，需要光流和 TOF 支持。

3. 角度修正 (Trim)

   -  翻滚角修正 (Roll Trim)：用于弥补传感器水平安装误差。
   -  俯仰角修正 (Pitch Trim)：用于弥补传感器水平安装误差。

注意，在自动模式下，油门摇杆变为高度控制摇杆。

高级飞行设置 (Advanced Flight Control)
~~~~~~~~~~~~~~~~~~~~~~~~~~~~~~~~~~~~~~

1. 最大倾角 (Max angle)：设置最大允许的俯仰和翻滚角度：roll/pitch。
2. 最大自旋速度 (Max yaw rate)：设置允许的偏航速度：yaw。
3. 最大油门 (Max thrust)：设置最大油门。
4. 最小油门 (Min thrust)：设置最小油门。
5. 压摆极限 (Slew limit)：防止油门骤降，油门低于该值时，下降速度将被限定。
6. 压摆率 (Slew rate)：油门到压摆极限之后的最大下降率。

遥控器设置 (Configure Input Device)
~~~~~~~~~~~~~~~~~~~~~~~~~~~~~~~~~~~~~~

按照提示绑定遥控器摇杆与各个控制通道：

cfclient 控制器配置

飞行数据 (Flight Data)
~~~~~~~~~~~~~~~~~~~~~~~~~~

驾驶仪可以看到当前飞机姿态，右下方显示对应的详细数据。

1. 目标角度 (Target)
2. 测量角度 (Actual)
3. 当前油门值 (Thrust)
4. 电机实际输出 (M1/M2/M3/M4)

在线参数修改
--------------------

**在线调整 PID 参数**

PID 参数调整
   
   cfclient PID 参数调整

**注意事项**

1. 修改的参数实时生效，避免了频繁烧录固件。
2. 可在代码中通过宏定义，配置哪些参数可被上位机实时修改。
3. 注意，参数在线修改仅用于调试，掉电不保存。

飞行数据监控
--------------------

**配置要监控的参数**

PID 参数调整

   监控参数配置

PID 参数调整

   参数配置区

**实时波形绘制**

陀螺仪加速度计实时数据监测：

PID 参数调整

   陀螺仪加速度计数据监测

螺旋桨方向
================

-  按照下图所示位置，安装 A、B 螺旋桨。
-  飞行器上电自检时，检查螺旋桨转向是否正确。

螺旋桨方向示图

   螺旋桨方向示图

起飞前检查
================

-  将小飞机头部朝前放置，尾部天线朝向自己；
-  将小飞机置于水平面上，待机身稳定时上电；
-  观察上位机水平面是否置平；
-  观察通信建立以后，小飞机尾部绿灯是否快速闪烁；
-  观察小飞机头部红灯是否熄灭，亮起代表电量不足；
-  轻推左手小油门，检查飞机是否能快速响应；
-  轻推右手方向，检查方向控制是否正确；
-  起飞吧！

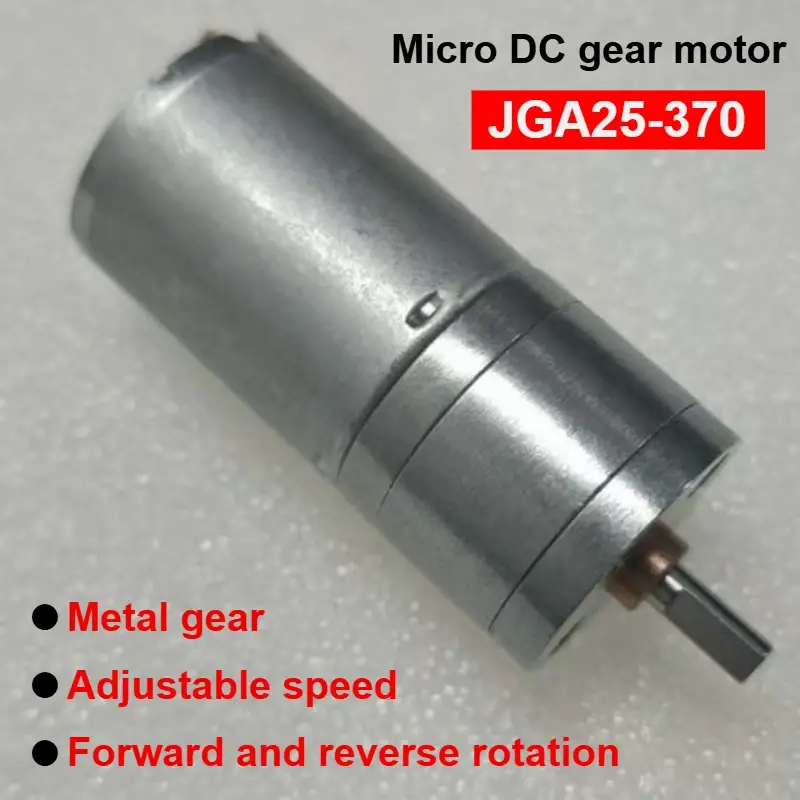
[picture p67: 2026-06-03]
docs/DataSheet/JGA25 motors/JGA25-370 Micro DC Gear Motor Instruction Manual_files/S6546711efc4242ad94e2cc70a7ba2a8cR.jpg

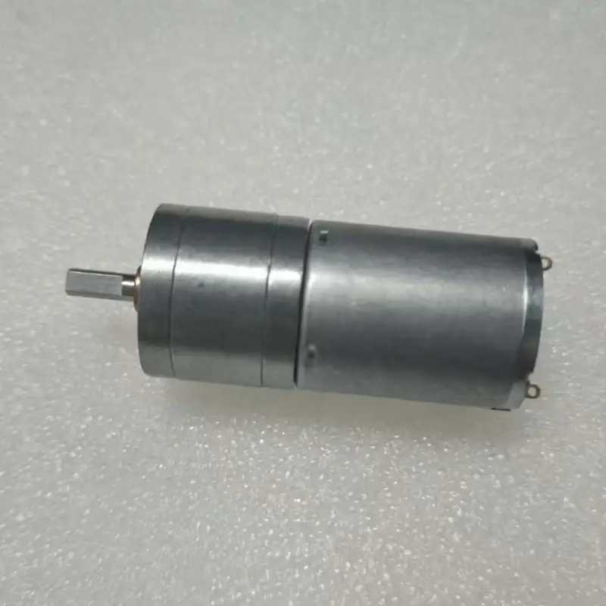
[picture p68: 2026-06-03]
docs/DataSheet/JGA25 motors/JGA25-370 Micro DC Gear Motor Instruction Manual_files/S282dba0329824d638628d8a61d146c56c.jpg

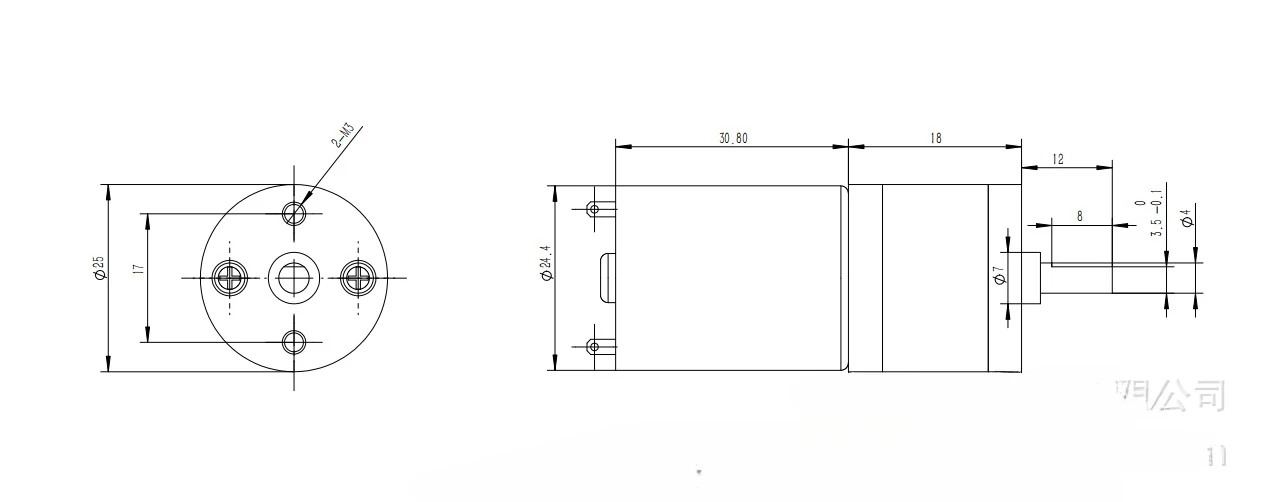
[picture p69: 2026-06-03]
docs/DataSheet/JGA25 motors/JGA25-370 Micro DC Gear Motor Instruction Manual_files/S135eaedba3fb419b9a2bc91ffd50b73aT.jpg

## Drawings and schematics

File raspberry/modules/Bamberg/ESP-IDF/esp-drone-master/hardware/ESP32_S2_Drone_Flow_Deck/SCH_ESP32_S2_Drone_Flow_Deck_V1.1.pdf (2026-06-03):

## Connectors

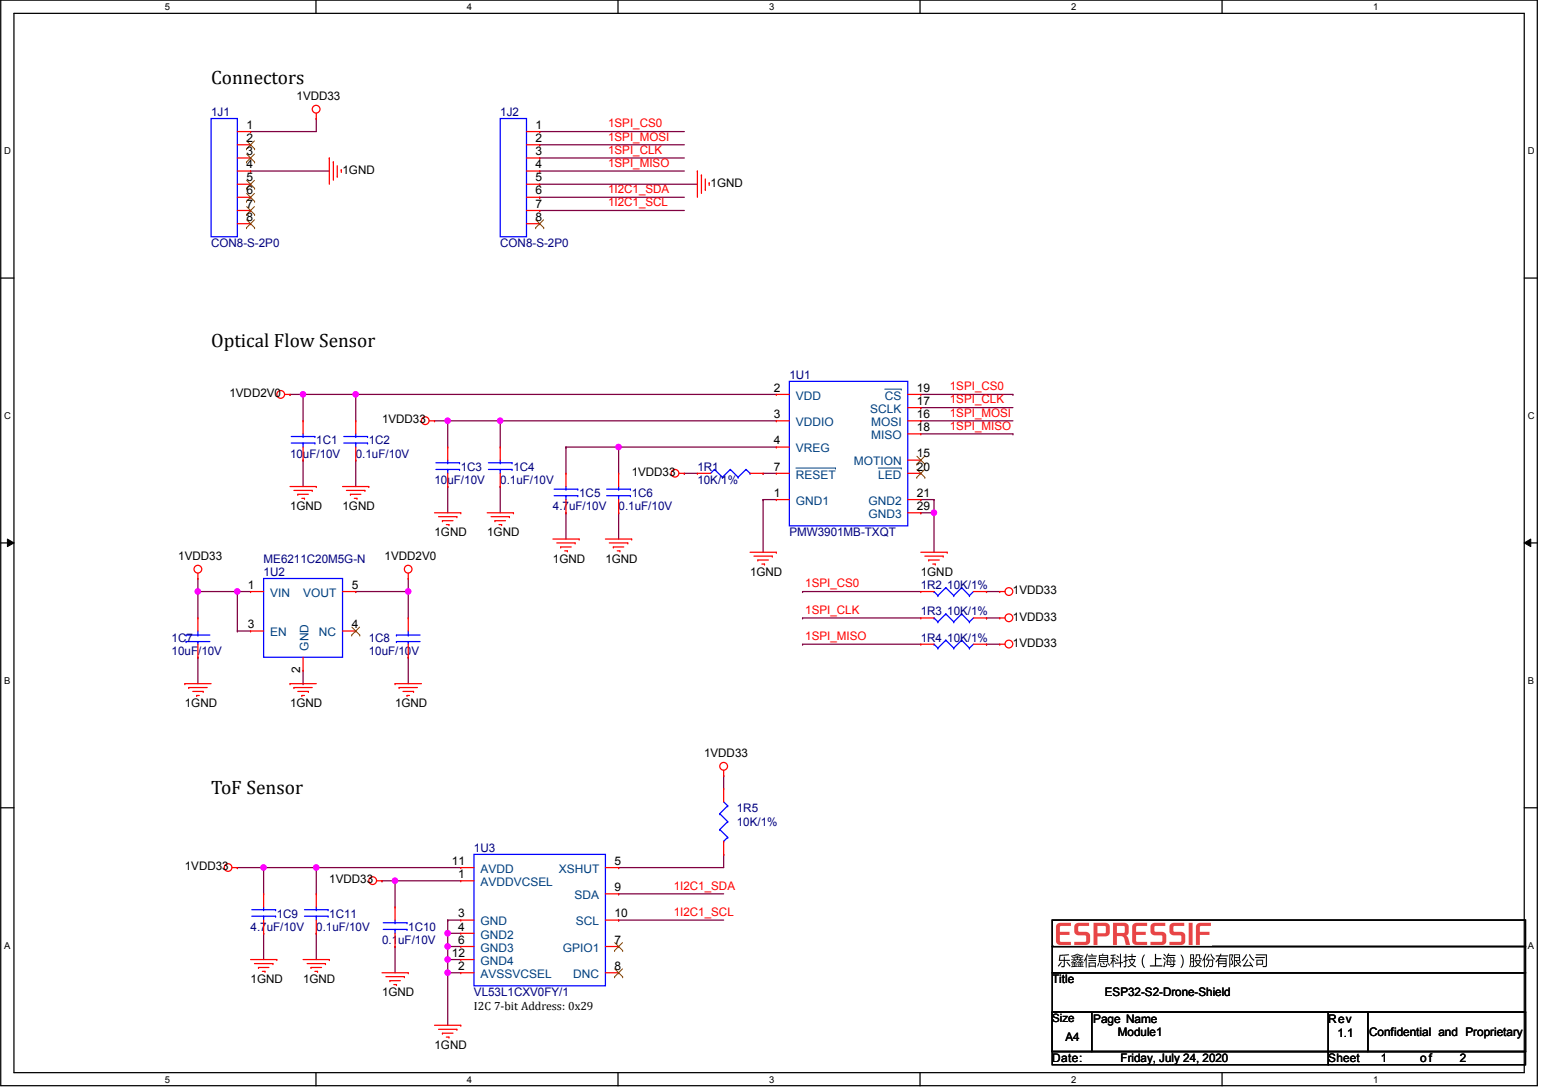
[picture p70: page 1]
I2C 7-bit Address: 0x29; ToF Sensor; 1SPI_CLK; 1SPI_MOSI; 1SPI_CS0; 1SPI_MISO; 1I2C1_SDA 1I2C1_SCL; 1I2C1_SDA; 1I2C1_SCL; 1VDD33; 1GND; 1VDD2V0; Title; Size; Page Name; Rev; Date:; Sheet; ESP32-S2-Drone-Shield; Friday, July 24, 2020; Module1; VL53L1CXV0FY/1; AVDDVCSEL 1; AVSSVCSEL 2; GND 3 GND2 4; XSHUT; GND3 6; DNC; SDA; SCL; AVDD 11; GND4 12; GPIO1; CON8-S-2P0; PMW3901MB-TXQT; GND1 1; VDD 2; VDDIO 3; VREG 4; RESET 7; MOTION; MOSI; 16 SCLK; MISO; LED; GND3; 29 GND2; VIN 1; GND; VOUT

Optical Flow Sensor

Confidential and Proprietary

## Connectors

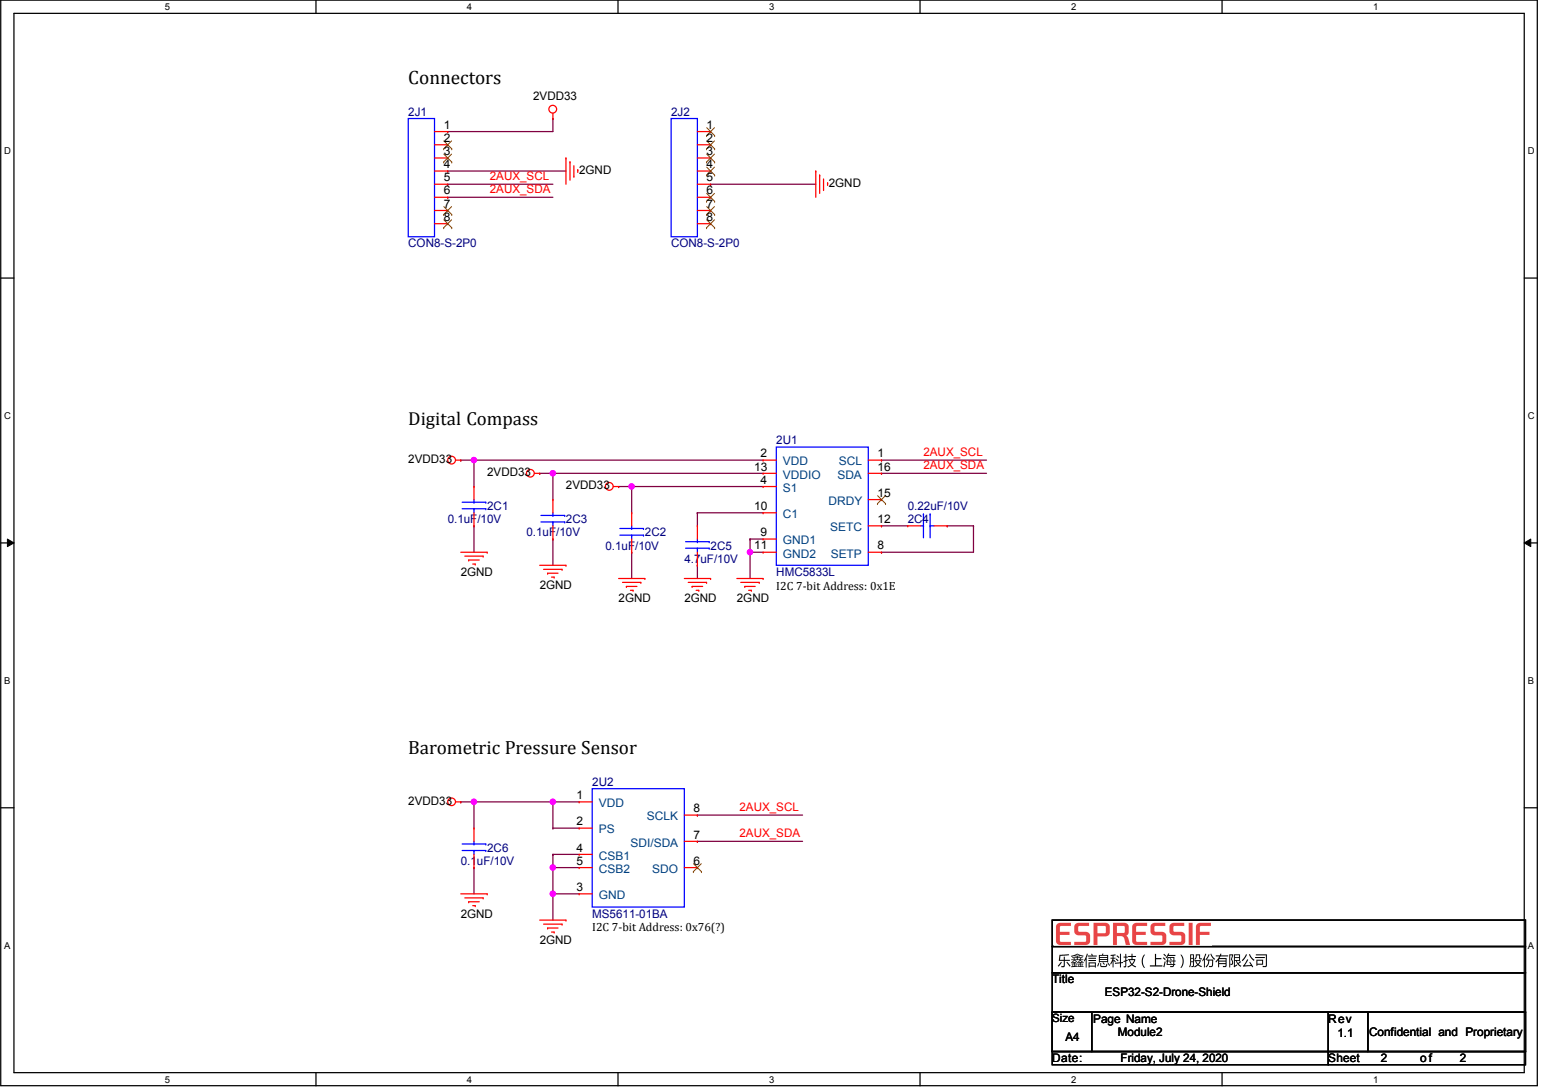
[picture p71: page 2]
Digital Compass; I2C 7-bit Address: 0x1E; I2C 7-bit Address: 0x76(?); 2AUX_SCL 2AUX_SDA; 2AUX_SCL; 2AUX_SDA; 2VDD33; 2GND; Title; Size; Page Name; Rev; Date:; Sheet; ESP32-S2-Drone-Shield; Friday, July 24, 2020; Module2; CON8-S-2P0; VDD 1; GND 3; CSB1 4; CSB2 5; SDO; SDI/SDA; SCLK; HMC5833L; SCL; 1 VDD 2; SETP; 8 GND1 9; GND2 11; SETC; VDDIO 13; DRDY; SDA

Barometric Pressure Sensor

Confidential and Proprietary

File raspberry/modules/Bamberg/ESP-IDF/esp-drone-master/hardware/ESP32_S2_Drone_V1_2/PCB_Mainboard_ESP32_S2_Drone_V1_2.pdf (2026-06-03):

100.0mm

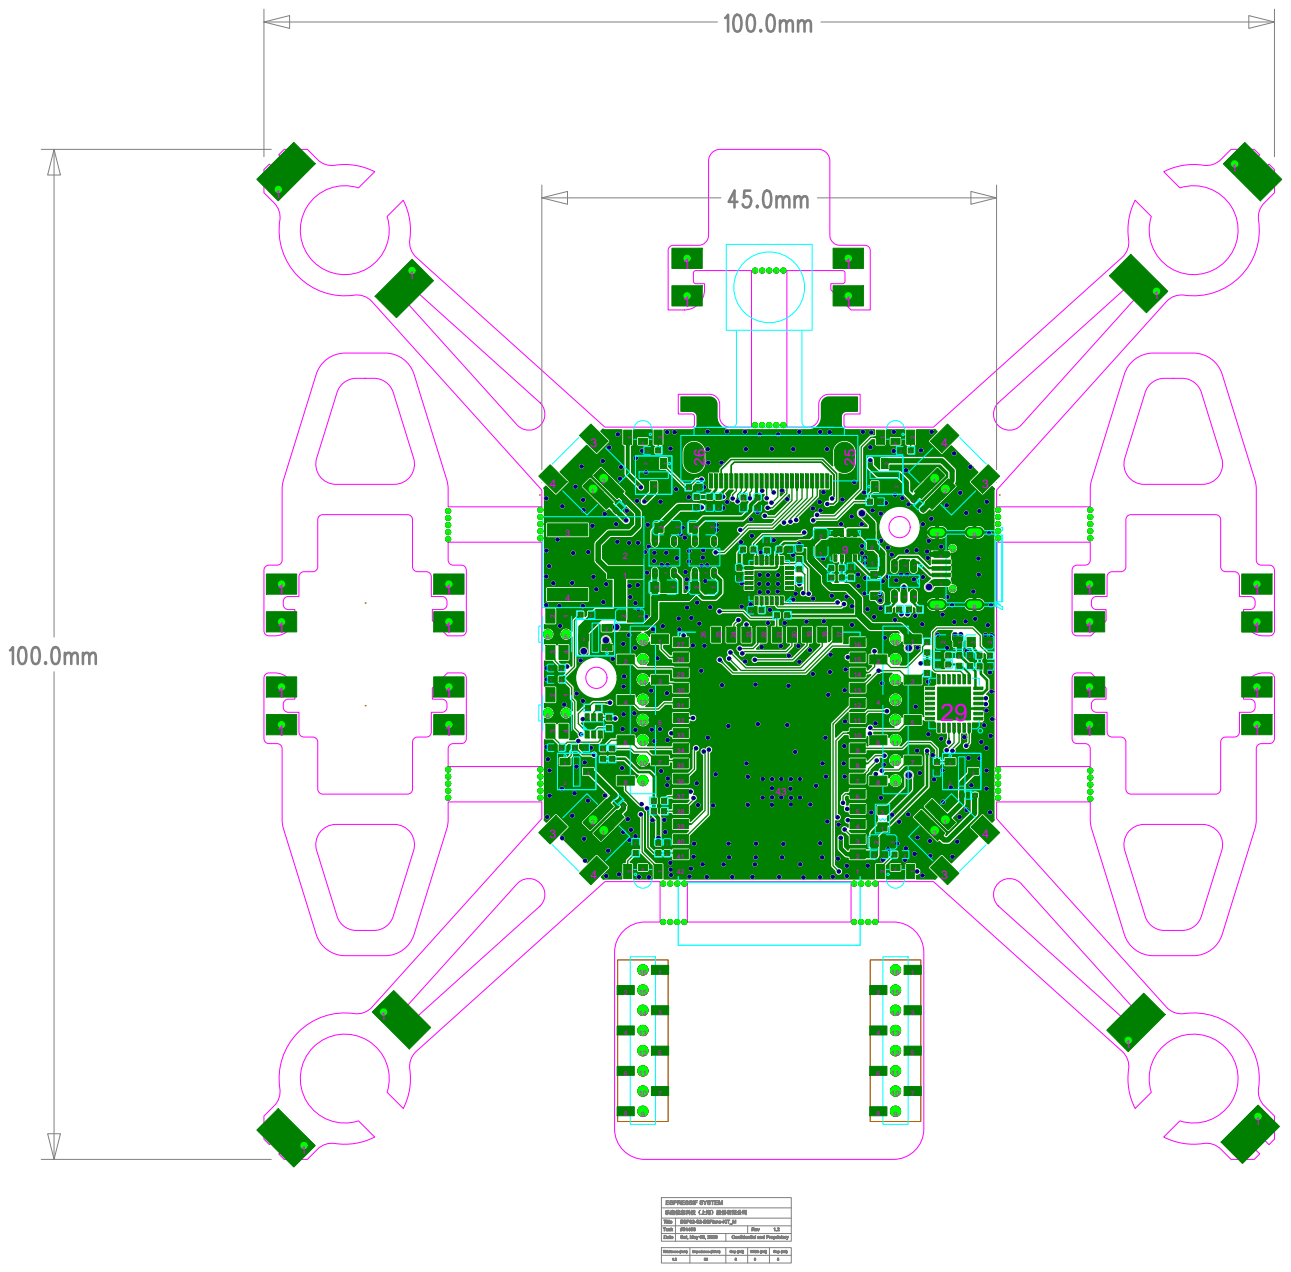
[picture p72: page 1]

100.0mm

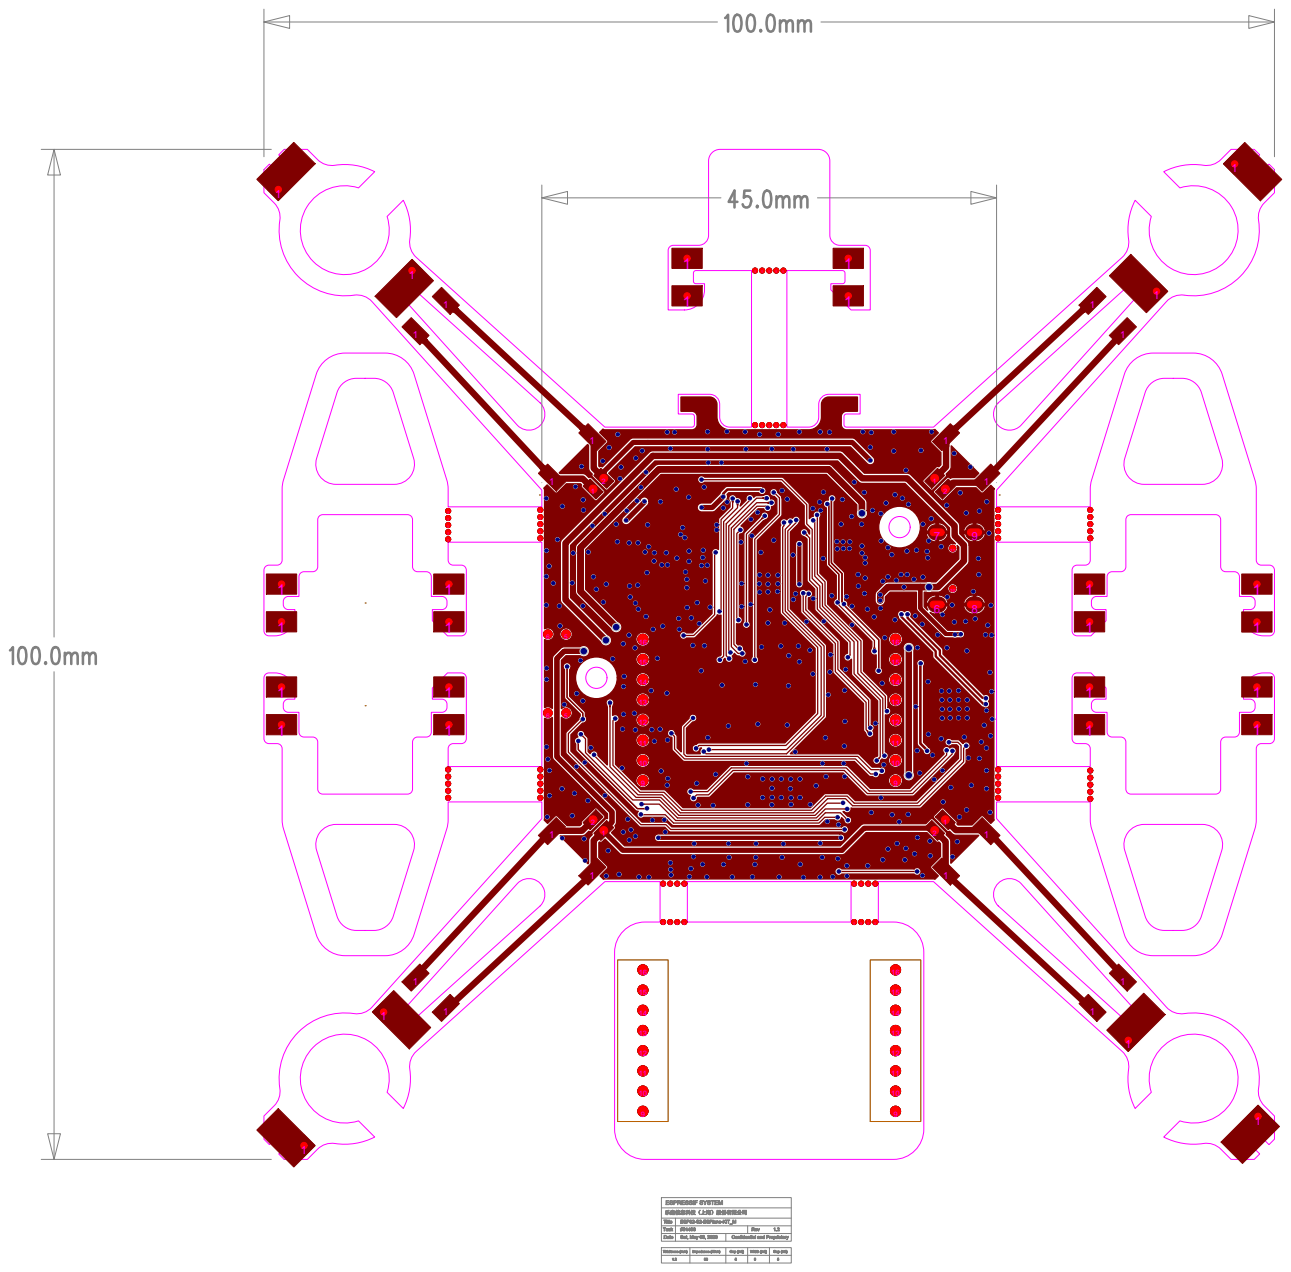
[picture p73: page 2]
Impedance (Ohm); Width (mil); Gap (mil) 5; Date; Task; Title; ESPRESSIF SYSTEM; Sat, May 09, 2020; Confidential and Proprietary; ESP32-S2-ESPlane-KIT_M; Rev; Thickness (mm); Gap (mil); H59H⁵⁹x1; H60H⁶⁰x1; H61H⁶¹x1; H62H⁶²x1; H63H⁶³x1; H65H⁶⁵x1; H66H⁶⁶x1; H67H⁶⁷x1; H68H⁶⁸x1; H69H⁶⁹x1; H70H⁷⁰x1; H71H⁷¹x1; H72H⁷²x1; H58H⁵⁸x1; H73H⁷³x1; H1H¹x1

乐鑫信息科技（上海）股份有限公司

100.0mm

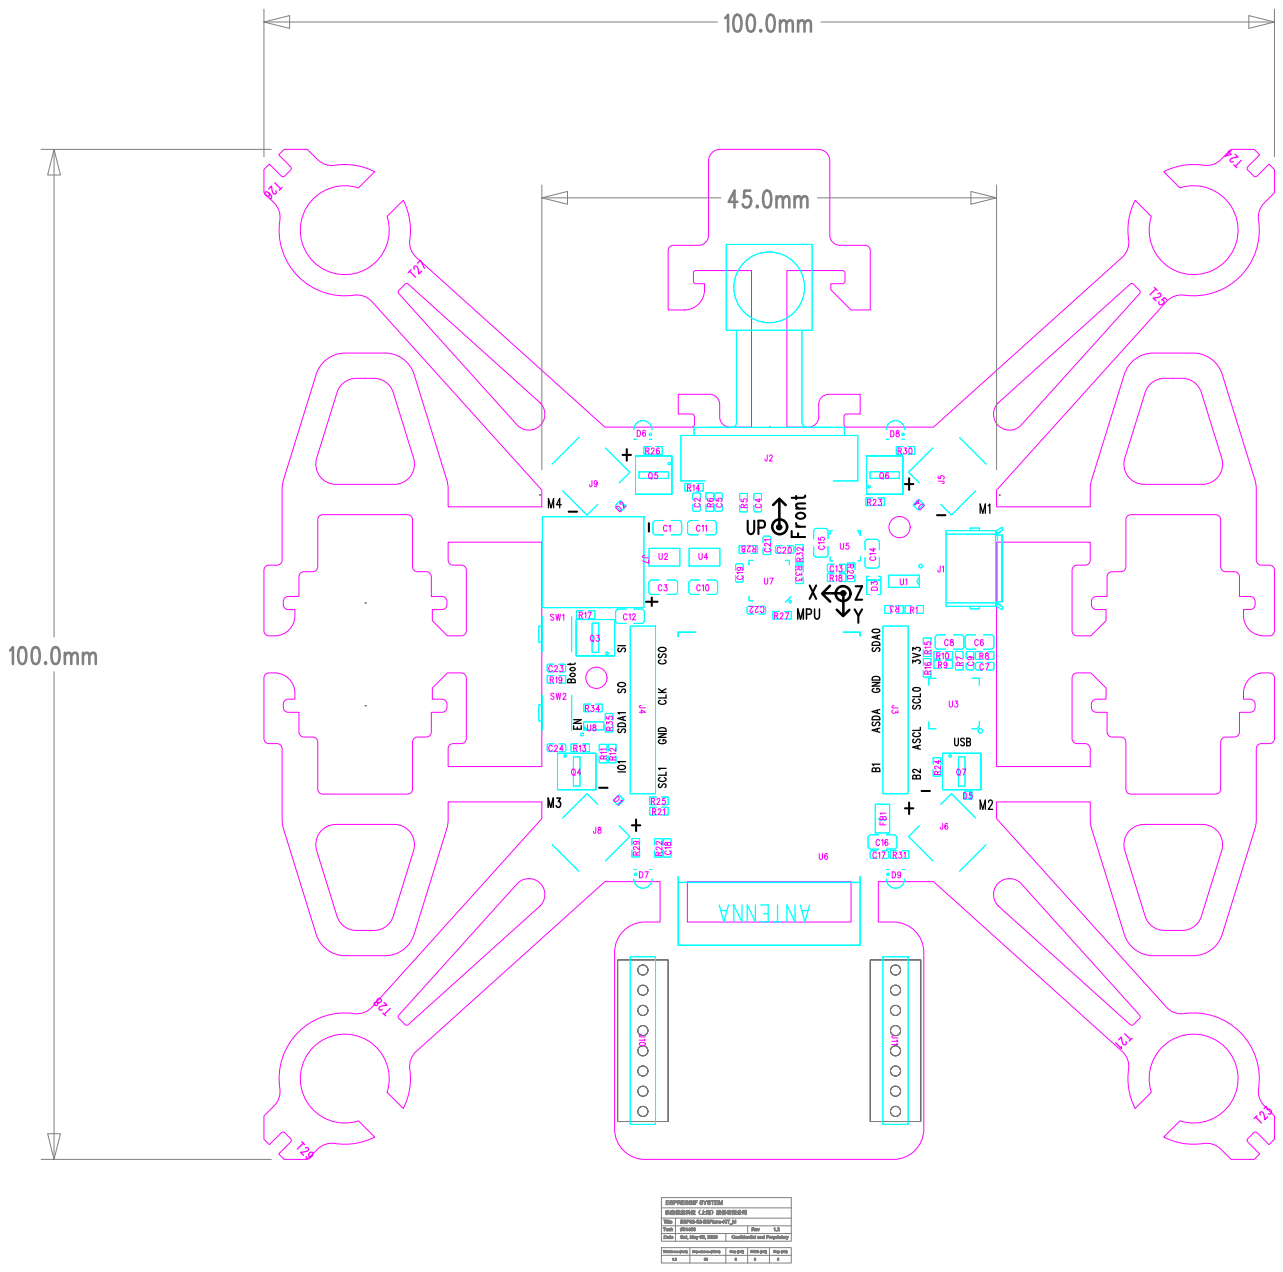
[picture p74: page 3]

100.0mm

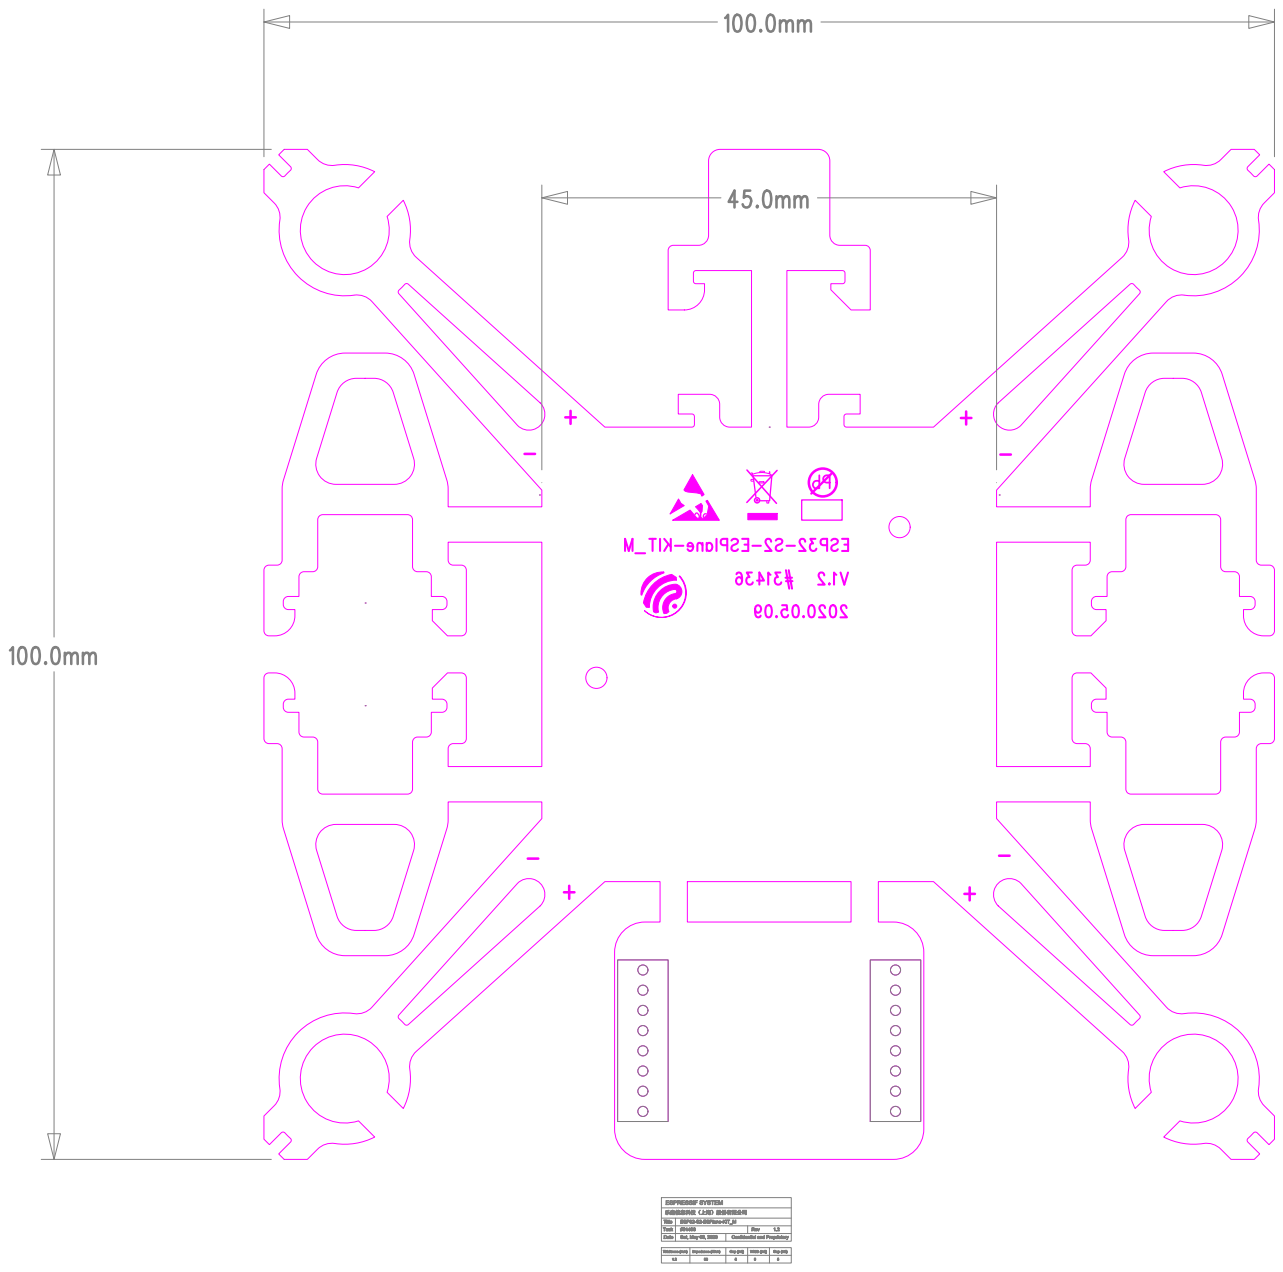
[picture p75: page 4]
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

乐鑫信息科技（上海）股份有限公司

100.0mm

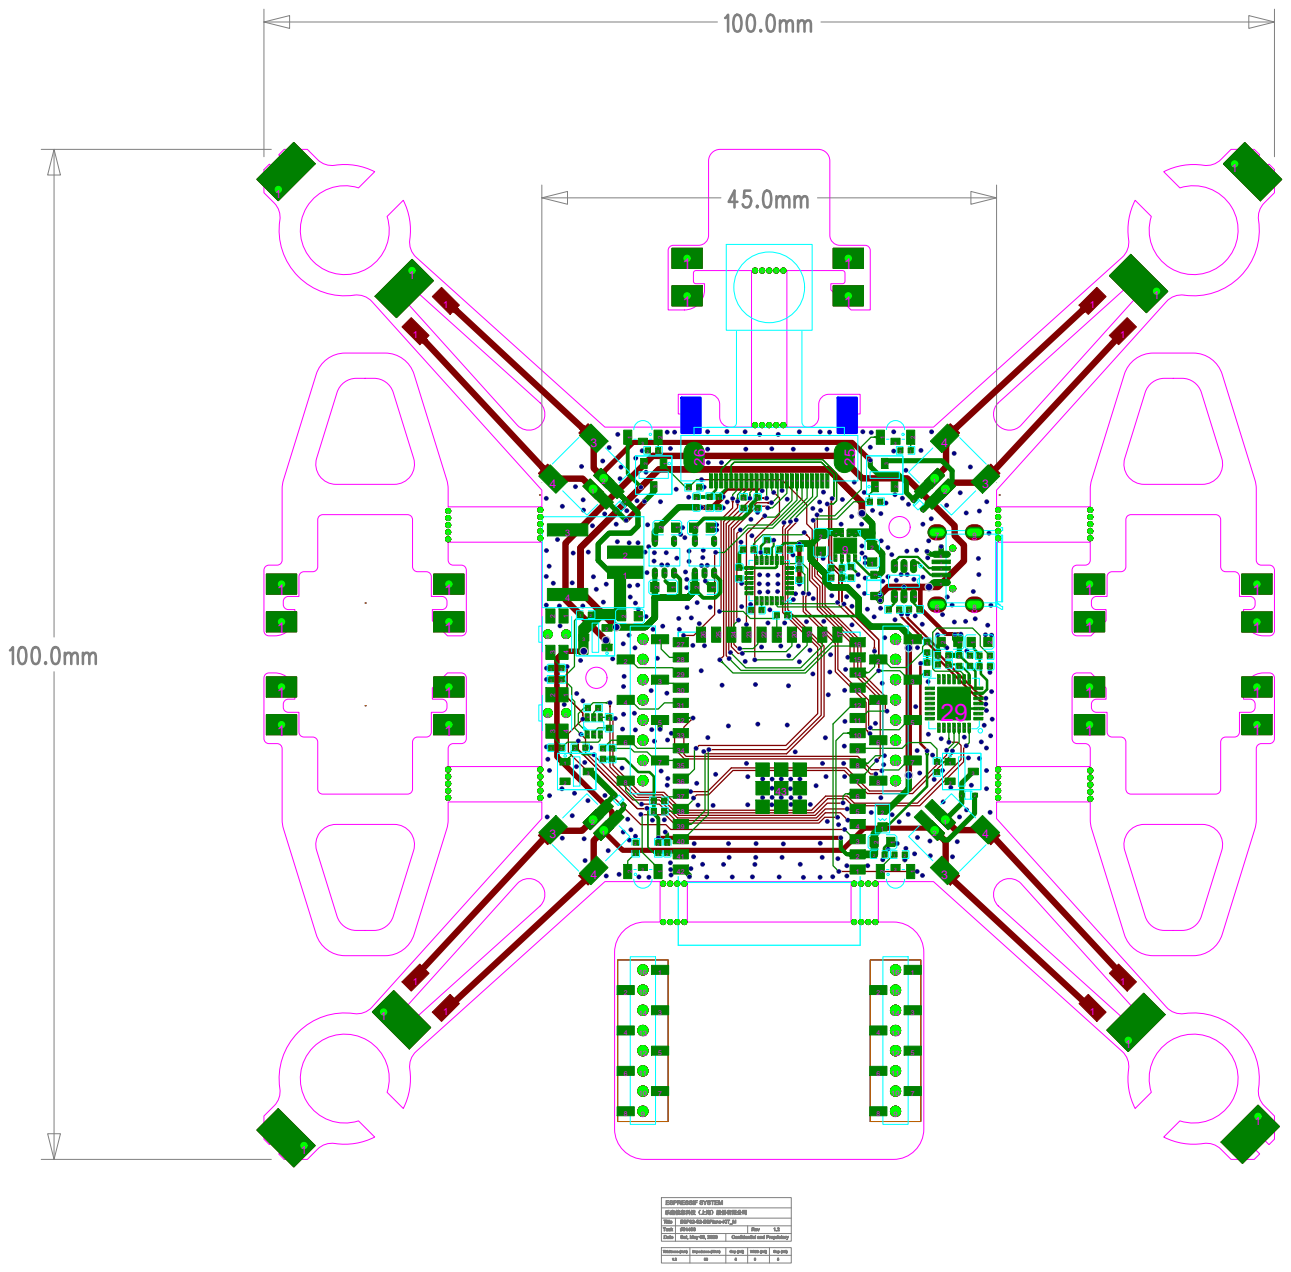
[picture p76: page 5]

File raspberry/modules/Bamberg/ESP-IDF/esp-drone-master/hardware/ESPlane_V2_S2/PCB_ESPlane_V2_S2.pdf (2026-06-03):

45.0mm

J2J2x1 | J2x2 | J2x3 | J2x4 | J2x5 | J2x6 | J2x7 | J2x8 | J2x9 | J2x10 | J2x11 | J2x12 | J2x13 | J2x14 | J2x15 | J2x16 | J2x17 | J2x18 | J2x19 | J2x20 | J2x21 | J2x22 | J2x23 | J2x24 J2x26 | J2x25

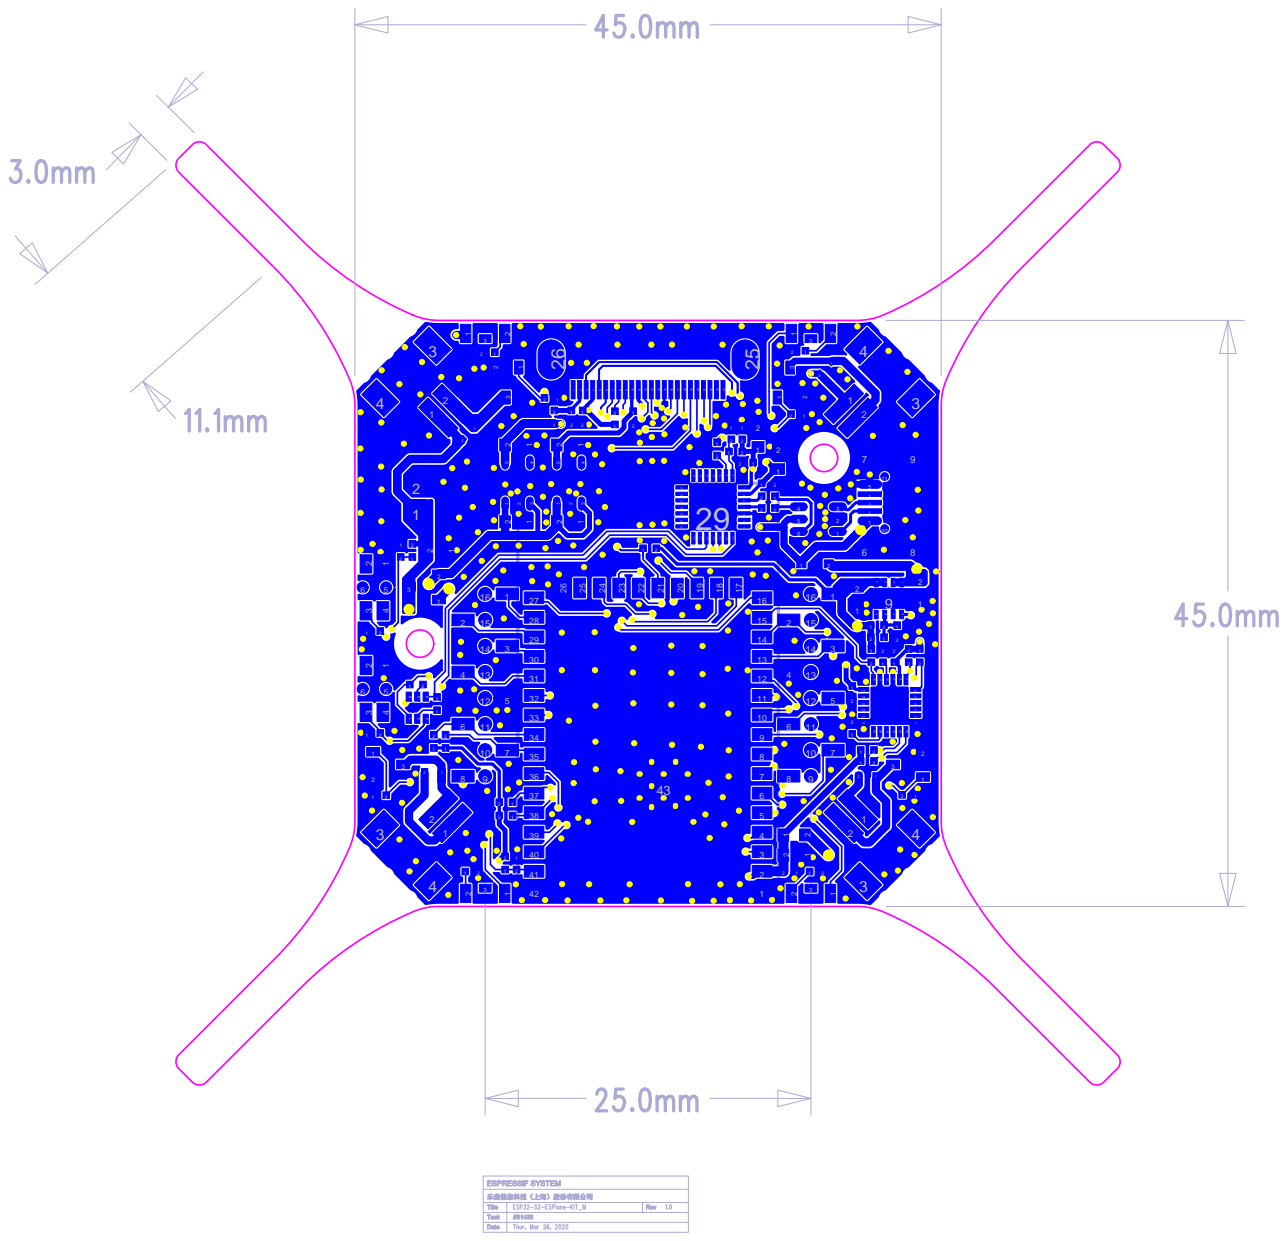
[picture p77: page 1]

45.0mm

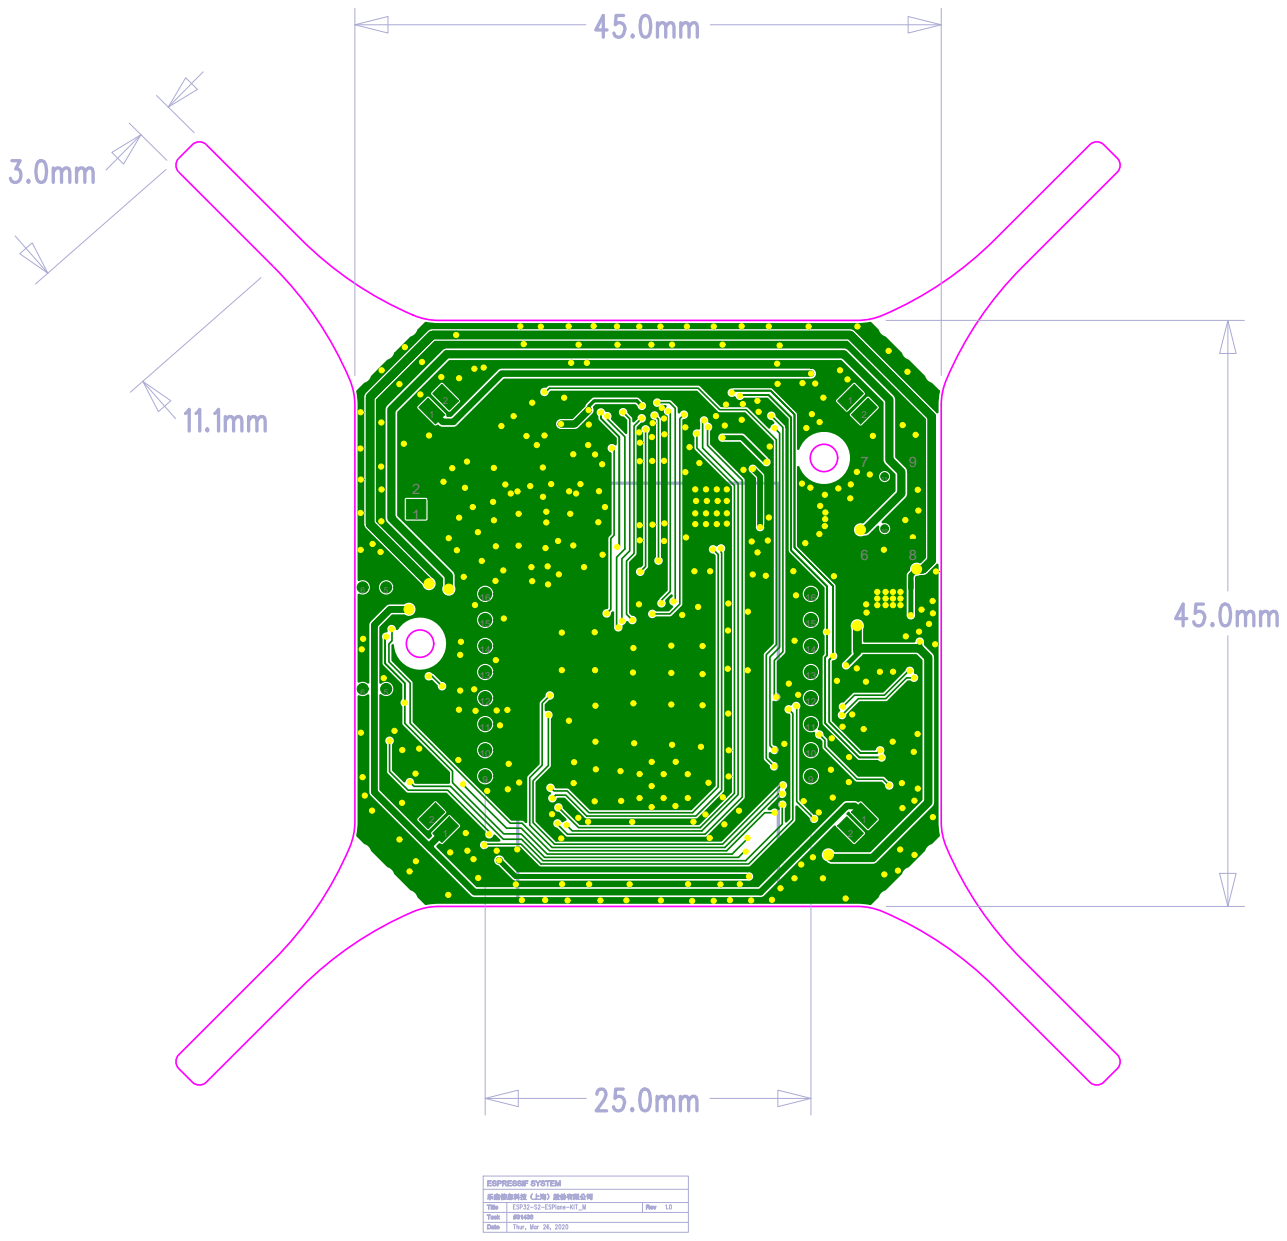
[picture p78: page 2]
Title; ESP32-S2-ESPlane-KIT_M; ESPRESSIF SYSTEM; Task; Date; Thur, Mar 26, 2020; Rev; SW1 SW¹x6; SW¹x5; SW2 SW²x6; SW²x5

乐鑫信息科技（上海）股份有限公司

45.0mm
J2

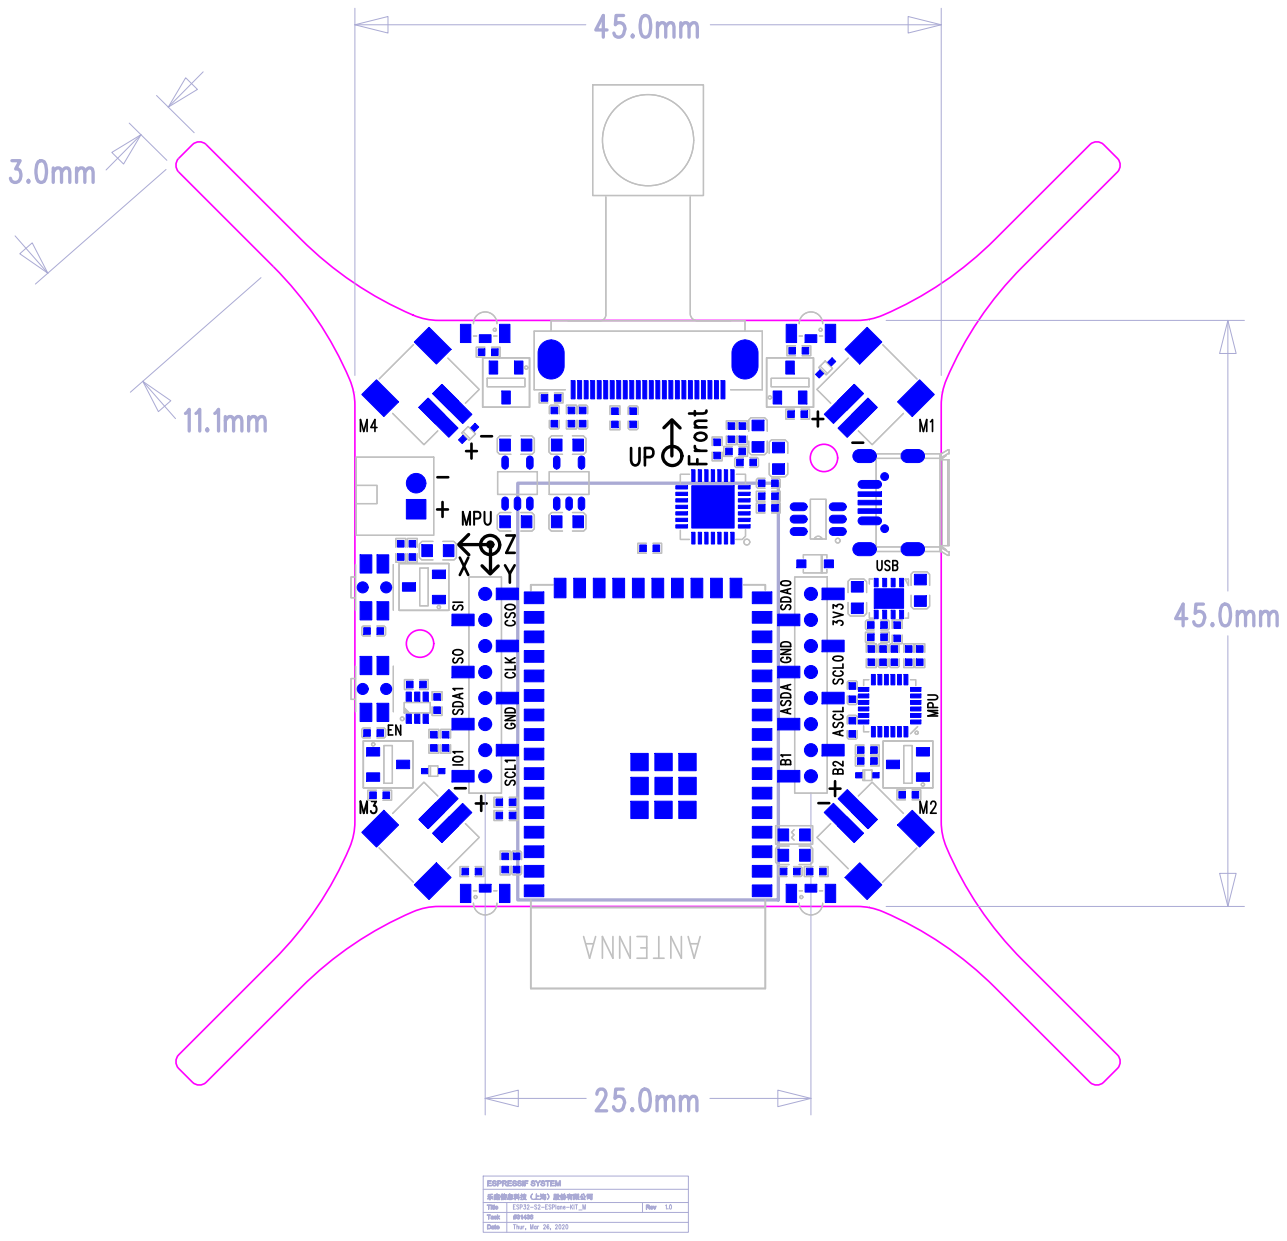
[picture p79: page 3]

45.0mm

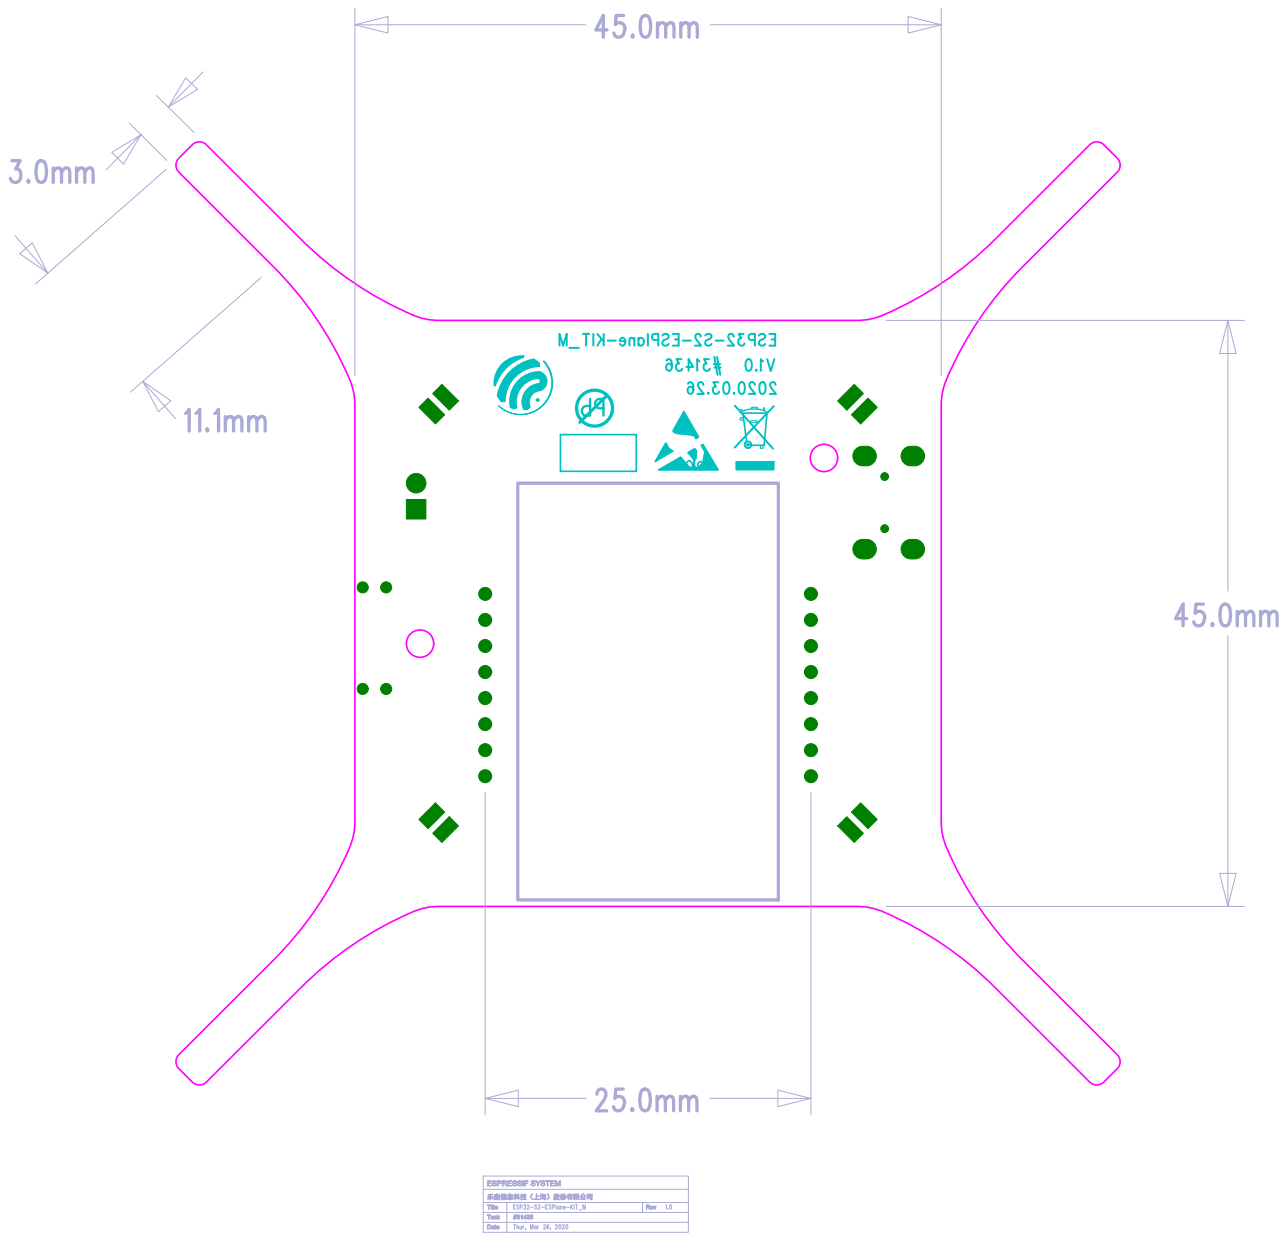
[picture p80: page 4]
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

乐鑫信息科技（上海）股份有限公司

45.0mm
J2

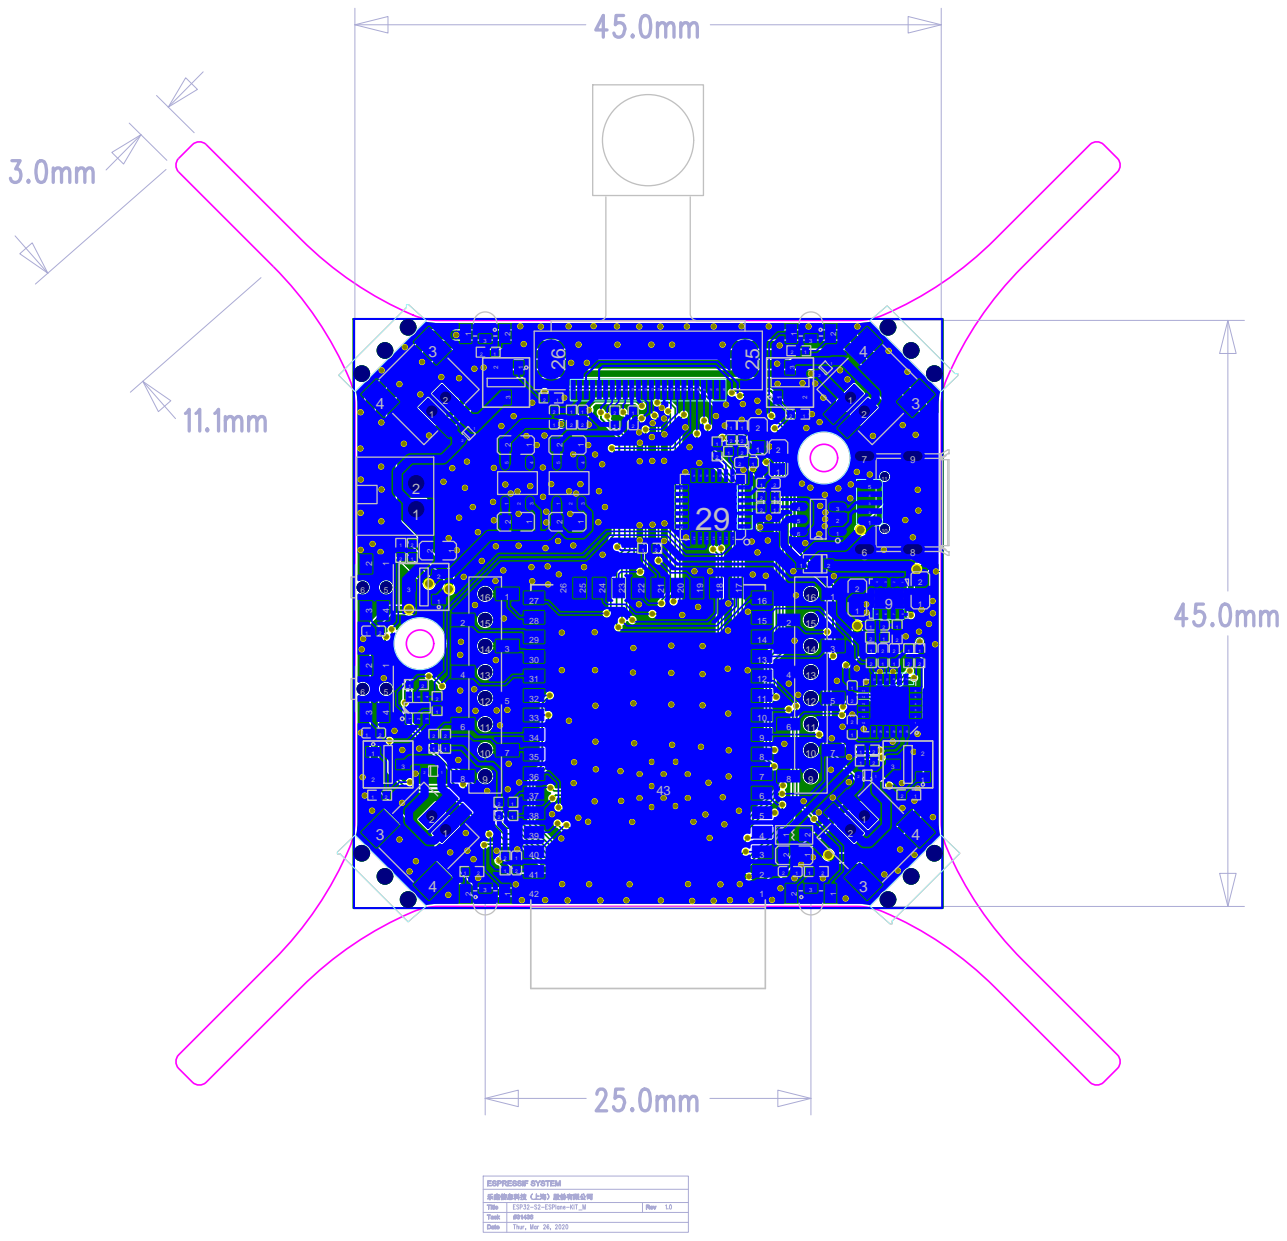
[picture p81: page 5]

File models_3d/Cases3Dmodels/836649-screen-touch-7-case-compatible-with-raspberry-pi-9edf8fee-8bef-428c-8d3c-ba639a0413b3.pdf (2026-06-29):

## Screen touch 7 Case compatible

Model files; Summary; Gonky kong; updated 8. 4. 2024 | published 8. 4. 2024; switch.stl; 3D MODEL ONLY

with Raspberry Pi

VIEW IN BROWSER (https://printables.com/model/836649-screen-touch-7-case-compatible-with-raspberry-pi)

a case from Screen touch 7" compatible with Raspberry Pi

Gadgets (https://printables.com/model?categoryId=21) > Photo & Video (https://printables.com/model?categoryId=26)

A simple case from 7 inch LCD touch screen, HDMI-compatible, 1024x600
resolution, compatible with Raspberry Pi

https://es.aliexpress.com/item/1005006329834534.html?
spm=a2g0o.productlist.main.3.4c364946xZniBl&algo_pvid=2853d126-
d253-41ff-904c-ef57fc74f749&algo_exp_id=2853d126-d253-41ff-904c-
ef57fc74f749-1&pdp_npi=4%40dis%21EUR%2127.63%2127.63%21%21%21212.04%21212.04%21%40211b600417125764518143163e5f80%2112000036783460982%21sea%21ES%21729059620%21&curPageLogUid=jVF33XXaT6SP&utparam-
url=scene%3Asearch%7Cquery_from%3A (https://es.aliexpress.com/item/1005006329834534.html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)

## License

This work is licensed under a
Creative Commons (4.0 International License)

Attribution-NonCommercial (http://creativecommons.org/licenses/by-nc/4.0/)

✖ | Sharing without ATTRIBUTION
✔ | Remix Culture allowed
✖ | Commercial Use
✖ | Free Cultural Works
✖ | Meets Open Definition

screen-touch-7-back.3mf

screen-touch-7-front.3mf

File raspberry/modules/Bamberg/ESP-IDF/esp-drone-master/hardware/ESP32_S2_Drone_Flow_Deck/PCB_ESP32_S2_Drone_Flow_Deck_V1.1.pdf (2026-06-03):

# 1C10¹C¹⁰x1 1C¹⁰x2

# 1C71C⁷x1 1C⁷x2

2C4²C⁴x1 2C⁴x2; 1C11C¹x2; 1C¹x1; 1C11 1C¹¹x1; 1C¹¹x2; 1C21C²x2; 1C²x1; 1C31C³x2; 1C³x1; 1C41C⁴x2; 1C⁴x1; 1C51C⁵x2; 1C⁵x1; 1C61C⁶x2; 1C⁶x1; 1C81C⁸x1; 1C⁸x2; 1C91C⁹x1; 1C⁹x2; 1R11R¹x1; 1R¹x2; 1R21R²x2; 1R²x1; 1R31R³x2; 1R³x1; 1R41R⁴x2; 1R⁴x1; 1R51R⁵x1 1R⁵x2; 1U1 ¹U¹x1 1U¹x2 1U¹x3 1U¹x4 1U¹x5 1U¹x6 1U¹x7; 1U¹x8; 1U¹x9; 1U¹x10; 1U¹x11; 1U¹x12; 1U¹x13; 1U¹x14; 1U2 ¹U²x3; 1U²x2; 1U²x1 1U²x4; 1U²x5; 1U3¹U³x1 1U³x2 1U³x3 1U³x4 1U³x7; 1U³x6; 1U³x5 1U³x8 1U³x9 ¹U³x10 1U³x11; 1U³x12; 2C12C¹x2; 2C¹x1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

1J11J1x1 1J1x2 | 1J1x3 1J1x4 | 1J1x5 1J1x6 | 1J1x7 1J1x8 1J1x9 1J1x10 1J1x11 1J1x12 1J1x13 1J1x14 1J1x15

# 1J21J2x1


# #32336 Shield1

200724

#32336 Shield2 200724; Optical Flow; ToF; eCompass; Barometric; Front; 2C5 2C4²C⁴x1 2C⁴x2; 1C11C¹x2; 1C¹x1; 1C10¹C¹⁰x1 1C¹⁰x2; 1C11 1C¹¹x1; 1C¹¹x2; 1C21C²x2; 1C²x1; 1C31C³x2; 1C³x1; 1C41C⁴x2; 1C⁴x1; 1C51C⁵x2; 1C⁵x1; 1C61C⁶x2; 1C⁶x1; 1C71C⁷x1; 1C⁷x2; 1C81C⁸x1; 1C⁸x2; 1C91C⁹x1; 1C⁹x2; 1R11R¹x1; 1R¹x2; 1R21R²x2; 1R²x1; 1R31R³x2; 1R³x1; 1R41R⁴x2; 1R⁴x1; 1R51R⁵x1 1R⁵x2; 1U1 ¹U¹x1 1U¹x2 1U¹x3 1U¹x4 1U¹x5 1U¹x6 1U¹x7; 1U¹x8; 1U¹x9; 1U¹x10; 1U¹x11; 1U¹x12; 1U¹x13; 1U¹x14; 1U2 ¹U²x3; 1U²x2; 1U²x1 1U²x4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

# 1J1¹J1x9 1J1x10 1J1x11 1J1x12 1J1x13 1J1x14 1J1x15

1J2


# #32336 Shield1

200724

#32336 Shield2 200724; Optical Flow; ToF; eCompass; Barometric; Front; 2C4²C⁴x1 2C⁴x2; 1C11C¹x2; 1C¹x1; 1C10¹C¹⁰x1 1C¹⁰x2; 1C11 1C¹¹x1; 1C¹¹x2; 1C21C²x2; 1C²x1; 1C31C³x2; 1C³x1; 1C41C⁴x2; 1C⁴x1; 1C51C⁵x2; 1C⁵x1; 1C61C⁶x2; 1C⁶x1; 1C71C⁷x1; 1C⁷x2; 1C81C⁸x1; 1C⁸x2; 1C91C⁹x1; 1C⁹x2; 1R11R¹x1; 1R¹x2; 1R21R²x2; 1R²x1; 1R31R³x2; 1R³x1; 1R41R⁴x2; 1R⁴x1; 1R51R⁵x1 1R⁵x2; 1U1 ¹U¹x1 1U¹x2 1U¹x3 1U¹x4 1U¹x5 1U¹x6 1U¹x7; 1U¹x8; 1U¹x9; 1U¹x10; 1U¹x11; 1U¹x12; 1U¹x13; 1U¹x14; 1U2 ¹U²x3; 1U²x2; 1U²x1 1U²x4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

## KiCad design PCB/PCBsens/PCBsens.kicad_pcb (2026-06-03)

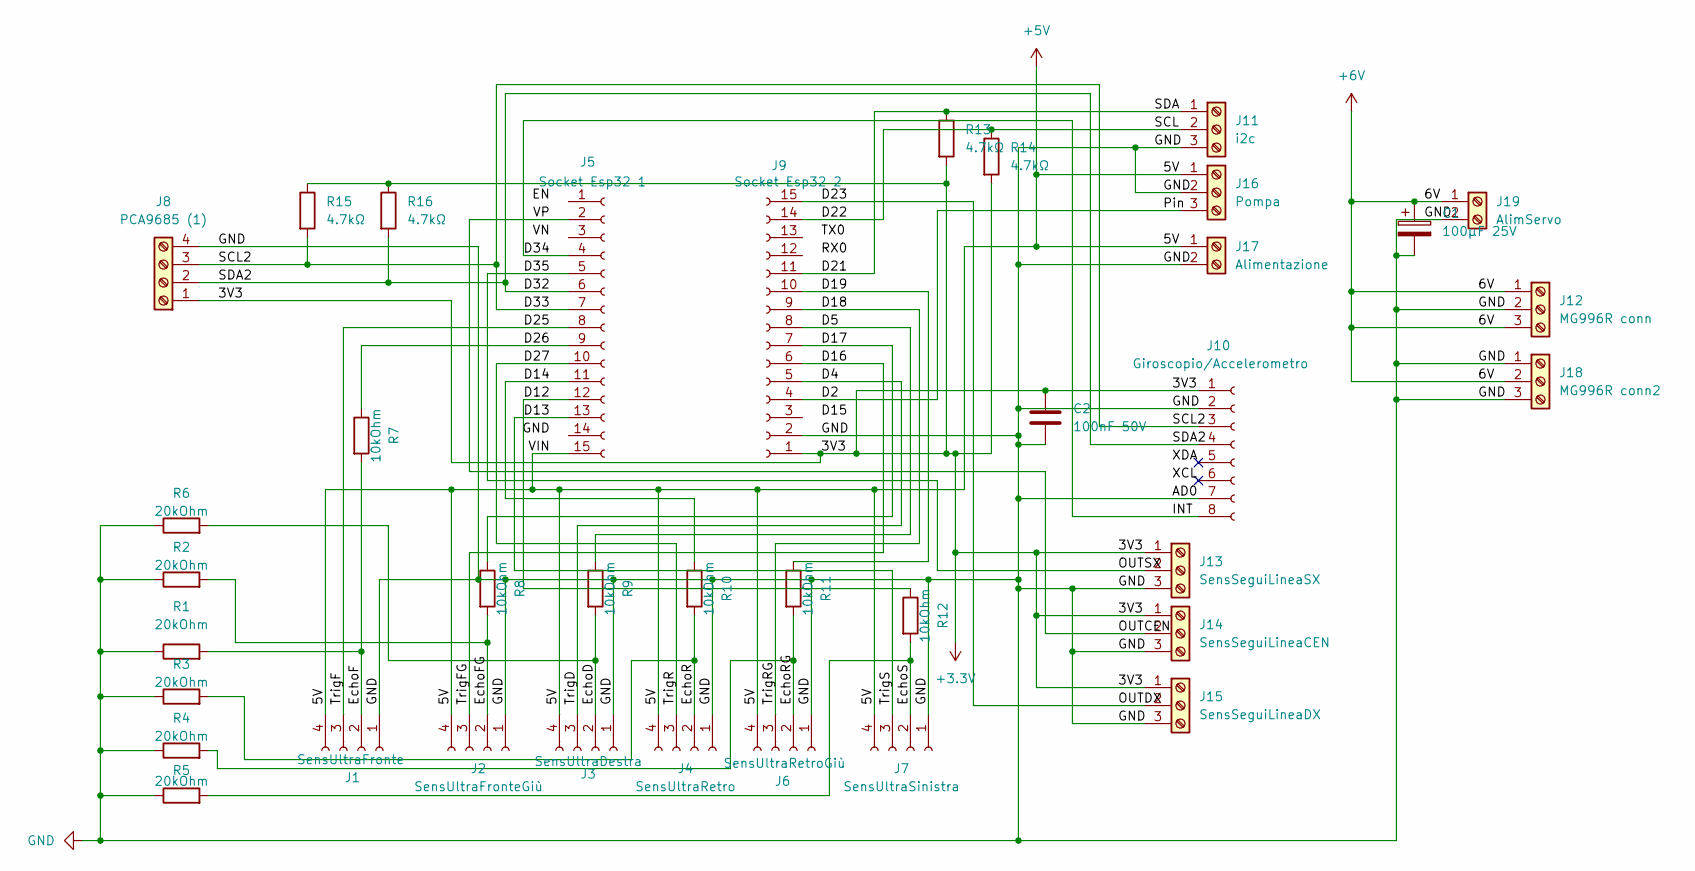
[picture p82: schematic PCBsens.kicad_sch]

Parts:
C1: 100µF 25V; CP_Radial_D8.0mm_P3.50mm
C2: 100nF 50V; C_Disc_D5.0mm_W2.5mm_P5.00mm
J1: SensUltraFronte; PinSocket_1x04_P2.54mm_Vertical
J2: SensUltraFronteGiù; PinSocket_1x04_P2.54mm_Vertical
J3: SensUltraDestra; PinSocket_1x04_P2.54mm_Vertical
J4: SensUltraRetro; PinSocket_1x04_P2.54mm_Vertical
J5: Socket Esp32 1; PinSocket_1x15_P2.54mm_Vertical
J6: SensUltraRetroGiù; PinSocket_1x04_P2.54mm_Vertical
J7: SensUltraSinistra; PinSocket_1x04_P2.54mm_Vertical
J8: PCA9685 (1); TerminalBlock_Phoenix_MKDS-1,5-4_1x04_P5.00mm_Horizontal
J9: Socket Esp32 2; PinSocket_1x15_P2.54mm_Vertical
J10: Giroscopio/Accelerometro; PinSocket_1x08_P2.54mm_Vertical
J11: i2c; TerminalBlock_Phoenix_MKDS-1,5-3_1x03_P5.00mm_Horizontal
J12: MG996R conn; TerminalBlock_Phoenix_MKDS-1,5-3_1x03_P5.00mm_Horizontal
J13: SensSeguiLineaSX; PinSocket_1x03_P2.54mm_Vertical
J14: SensSeguiLineaCEN; PinSocket_1x03_P2.54mm_Vertical
J15: SensSeguiLineaDX; PinSocket_1x03_P2.54mm_Vertical
J16: Pompa; TerminalBlock_Phoenix_MKDS-1,5-3_1x03_P5.00mm_Horizontal
J17: Alimentazione; TerminalBlock_Phoenix_MKDS-1,5-2_1x02_P5.00mm_Horizontal
J18: MG996R conn2; TerminalBlock_Phoenix_MKDS-1,5-3_1x03_P5.00mm_Horizontal
J19: AlimServo; TerminalBlock_Phoenix_MKDS-1,5-2_1x02_P5.00mm_Horizontal
R1, R2, R3, R4, R5, R6: 20kOhm; R_Axial_DIN0207_L6.3mm_D2.5mm_P7.62mm_Horizontal
R7, R8, R9, R10, R11, R12: 10kOhm; R_Axial_DIN0207_L6.3mm_D2.5mm_P7.62mm_Horizontal
R13, R14, R15, R16: 4.7kΩ; R_Axial_DIN0207_L6.3mm_D2.5mm_P7.62mm_Horizontal

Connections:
+3.3V: C2.1, J8.1, J9.1, J10.1, J13.1, J14.1, J15.1, R13.2, R14.2, R15.1, R16.1
+5V: J1.4, J2.4, J3.4, J4.4, J5.15, J6.4, J7.4, J16.1, J17.1
+6V: C1.1, J12.1, J12.3, J18.2, J19.1
/D2: J9.4, J16.3
/D4: J3.3, J9.5
/D5: J9.8, R9.1
/D12: J5.12, R12.1
/D13: J5.13, J7.3
/D14: J5.11, R10.1
/D16: J2.3, J9.6
/D17: J9.7, R8.1
/D18: J6.3, J9.9
/D19: J9.10, R11.1
/D21: J9.11, J11.1, R13.1
/D22: J9.14, J11.2, R14.1
/D23: J9.15, J15.2
/D25: J1.3, J5.8
/D26: J5.9, R7.1
/D27: J4.3, J5.10
/D32: J5.6, J8.2, J10.4, R16.2
/D33: J5.7, J8.3, J10.3, R15.2
/D34: J5.4, J10.8
/D35: J5.5, J13.2
/EchoD: J3.2, R6.2, R9.2
/EchoF: J1.2, R1.2, R7.2
/EchoFG: J2.2, R2.2, R8.2
/EchoR: J4.2, R3.2, R10.2
/EchoRG: J6.2, R4.2, R11.2
/EchoS: J7.2, R5.2, R12.2
/OUTCEN: J5.2, J14.2
GND: C1.2, C2.2, J1.1, J2.1, J3.1, J4.1, J6.1, J7.1, J8.4, J9.2, J10.2, J10.7, J11.3, J12.2, J13.3, J14.3, J15.3, J16.2, J17.2, J18.1, J18.3, J19.2, R1.1, R2.1, R3.1, R4.1, R5.1, R6.1

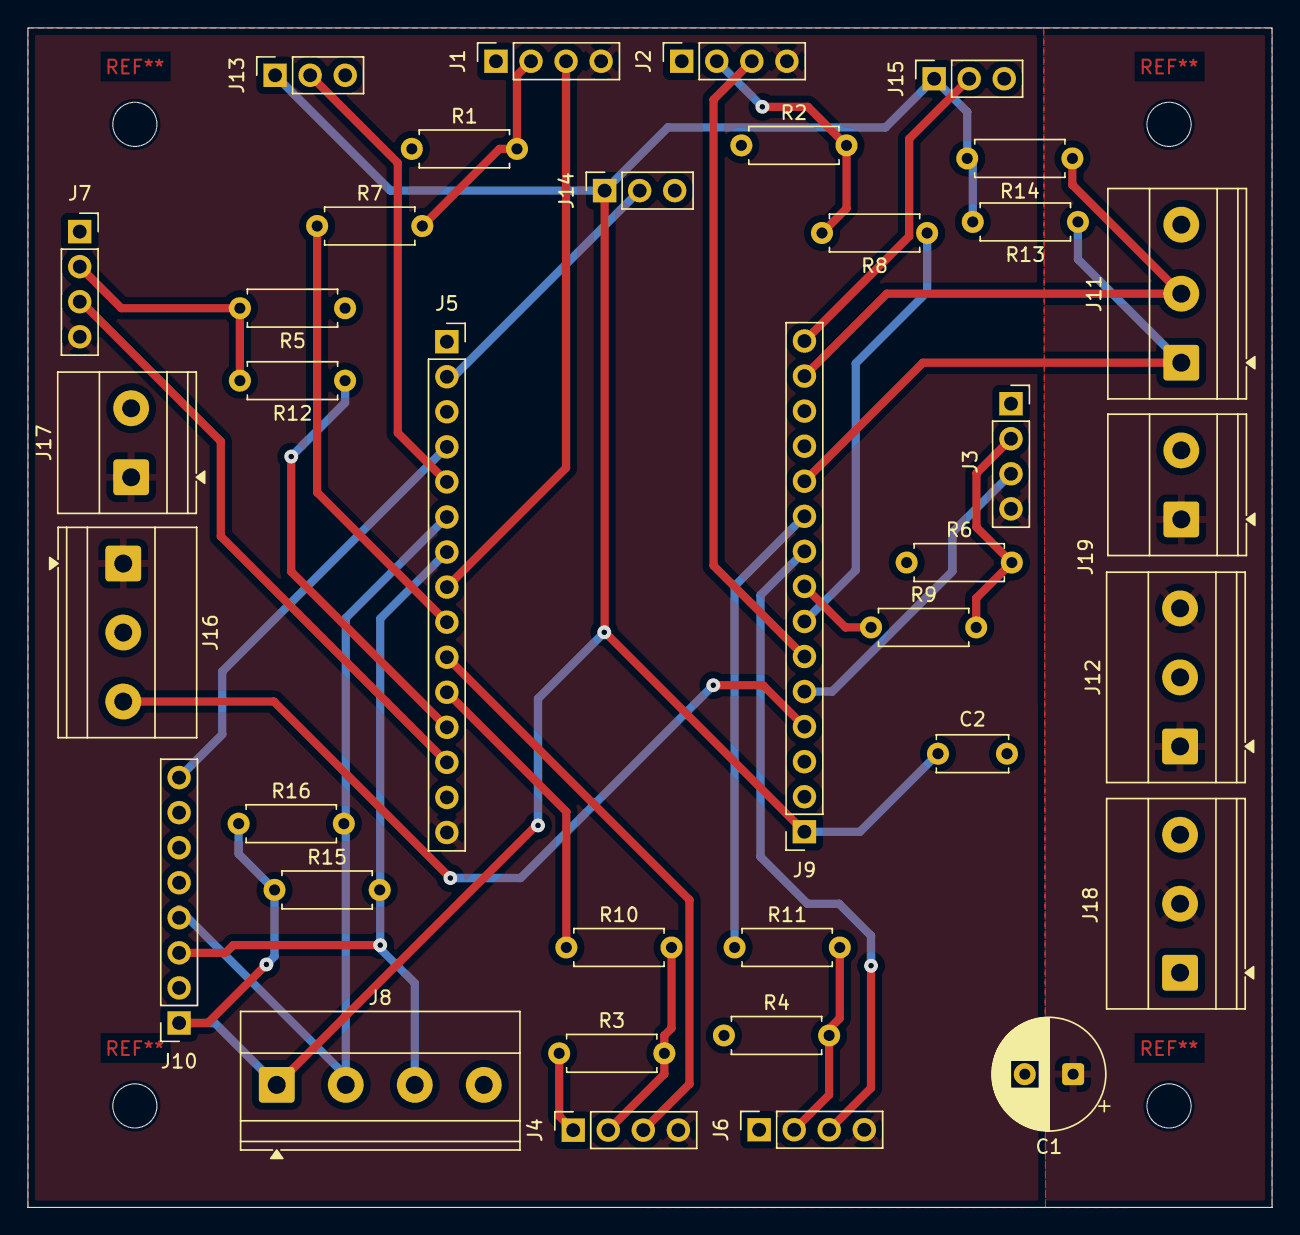
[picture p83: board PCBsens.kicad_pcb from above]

Board: 2 copper layers, 90.1 x 85.5 mm, 37 parts (0 on the bottom side), 31 nets.

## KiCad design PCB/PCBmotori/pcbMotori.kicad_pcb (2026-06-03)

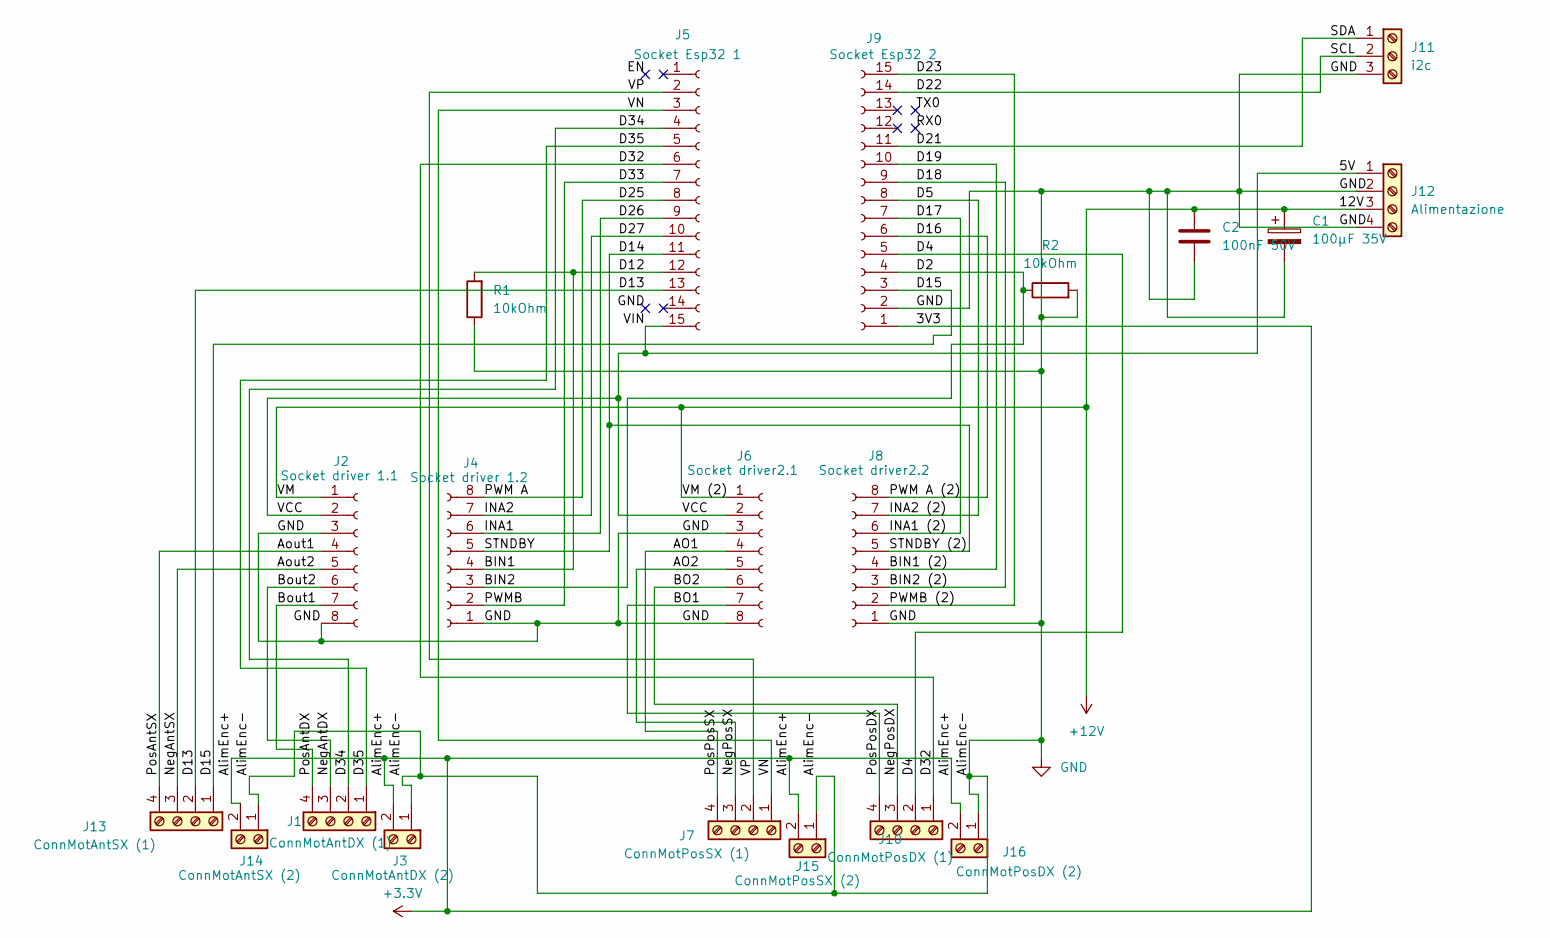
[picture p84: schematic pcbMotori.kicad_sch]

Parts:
C1: 100µF 35V; CP_Radial_D8.0mm_P3.50mm
C2: 100nF 50V; C_Disc_D5.0mm_W2.5mm_P5.00mm
J1: ConnMotAntDX (1); TerminalBlock_Phoenix_MKDS-1,5-4_1x04_P5.00mm_Horizontal
J2: Socket driver 1.1; PinSocket_1x08_P2.54mm_Vertical
J3: ConnMotAntDX (2); TerminalBlock_Phoenix_MKDS-1,5-2_1x02_P5.00mm_Horizontal
J4: Socket driver 1.2; PinSocket_1x08_P2.54mm_Vertical
J5: Socket Esp32 1; PinSocket_1x15_P2.54mm_Vertical
J6: Socket driver2.1; PinSocket_1x08_P2.54mm_Vertical
J7: ConnMotPosSX (1); TerminalBlock_Phoenix_MKDS-1,5-4_1x04_P5.00mm_Horizontal
J8: Socket driver2.2; PinSocket_1x08_P2.54mm_Vertical
J9: Socket Esp32 2; PinSocket_1x15_P2.54mm_Vertical
J10: ConnMotPosDX (1); TerminalBlock_Phoenix_MKDS-1,5-4_1x04_P5.00mm_Horizontal
J11: i2c; PinSocket_1x03_P2.54mm_Vertical
J12: Alimentazione; TerminalBlock_Phoenix_MKDS-1,5-4_1x04_P5.00mm_Horizontal
J13: ConnMotAntSX (1); TerminalBlock_Phoenix_MKDS-1,5-4_1x04_P5.00mm_Horizontal
J14: ConnMotAntSX (2); TerminalBlock_Phoenix_MKDS-1,5-2_1x02_P5.00mm_Horizontal
J15: ConnMotPosSX (2); TerminalBlock_Phoenix_MKDS-1,5-2_1x02_P5.00mm_Horizontal
J16: ConnMotPosDX (2); TerminalBlock_Phoenix_MKDS-1,5-2_1x02_P5.00mm_Horizontal
R1, R2: 10kOhm; R_Axial_DIN0207_L6.3mm_D2.5mm_P7.62mm_Horizontal

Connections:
+3.3V: J3.2, J9.1, J14.2, J15.2, J16.2
+12V: C1.1, C2.1, J2.1, J6.1, J12.3
/5V: J2.2, J5.15, J6.2, J12.1
/AO1: J6.4, J7.4
/AO2: J6.5, J7.3
/Aout1: J2.4, J13.4
/Aout2: J2.5, J13.3
/BIN1: J4.4, J5.12, R1.2
/BIN1 (2): J8.4, J9.10
/BIN2: J4.3, J9.4, R2.1
/BIN2 (2): J8.3, J9.9
/BO1: J6.7, J10.4
/BO2: J6.6, J10.3
/Bout1: J1.4, J2.7
/Bout2: J1.3, J2.6
/D4: J9.5, J10.2
/D5: J8.7, J9.8
/D13: J5.13, J13.2
/D14: J4.5, J5.11, J8.5
/D15: J9.3, J13.1
/D16: J8.8, J9.6
/D17: J8.6, J9.7
/D21: J9.11, J11.1
/D22: J9.14, J11.2
/D23: J8.2, J9.15
/D25: J4.8, J5.8
/D26: J4.6, J5.9
/D27: J4.7, J5.10
/D32: J5.6, J10.1
/D33: J4.2, J5.7
/D34: J1.2, J5.4
/D35: J1.1, J5.5
/VN: J5.3, J7.1
/VP: J5.2, J7.2
GND: C1.2, C2.2, J2.3, J2.8, J3.1, J4.1, J6.3, J6.8, J8.1, J9.2, J11.3, J12.2, J12.4, J14.1, J15.1, J16.1, R1.1, R2.2

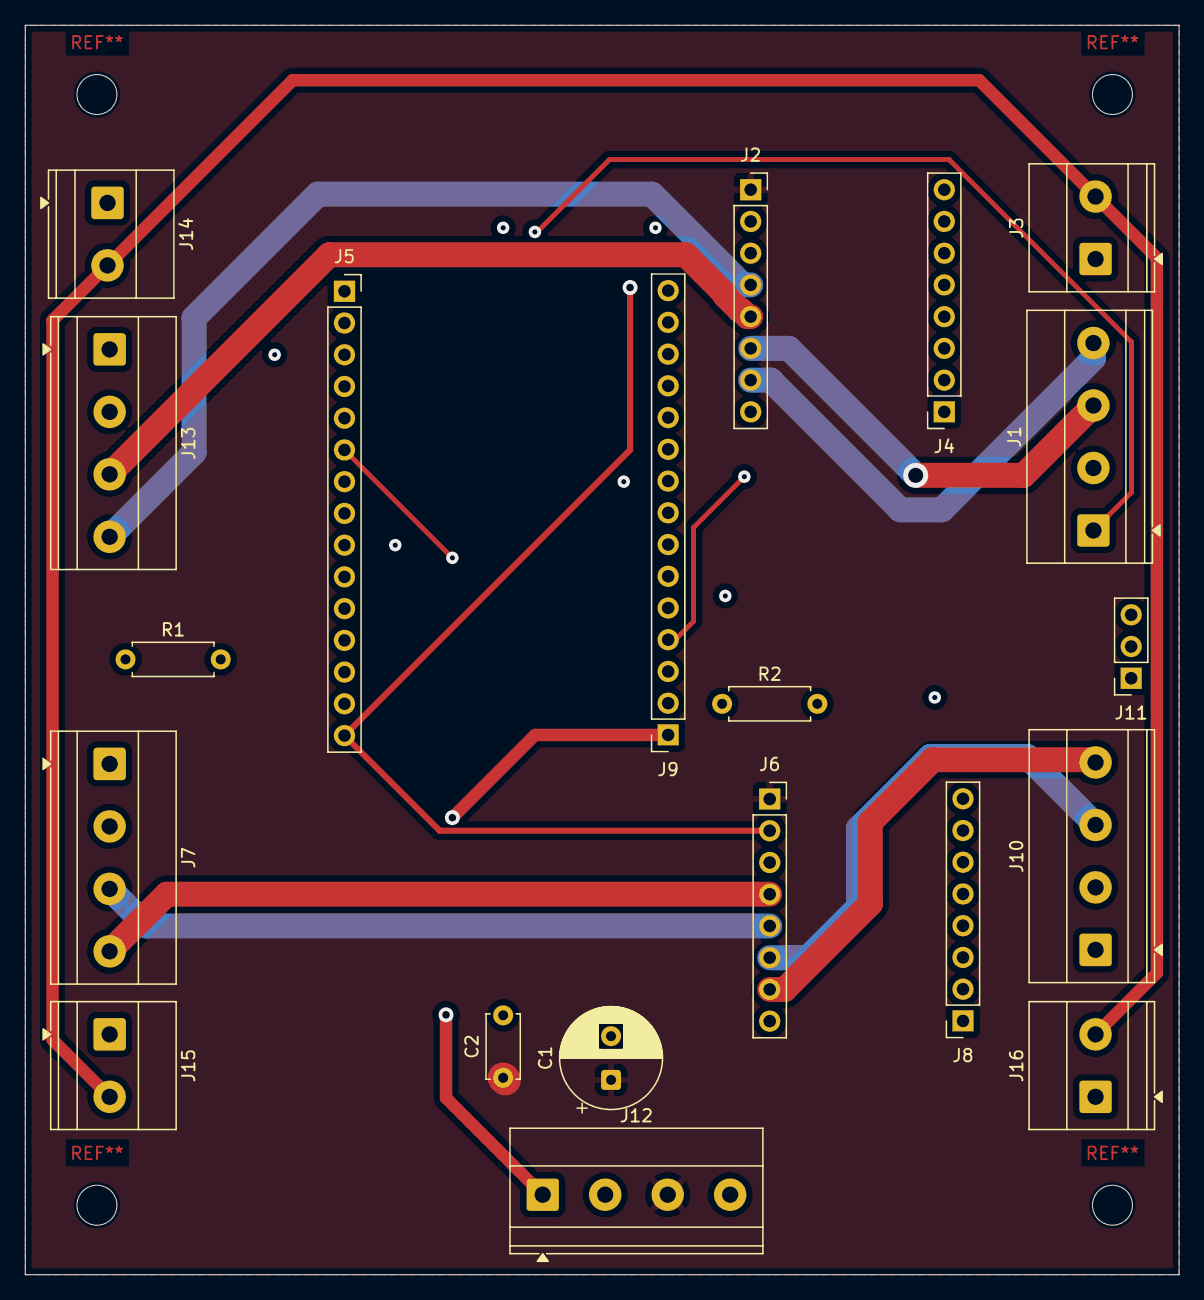
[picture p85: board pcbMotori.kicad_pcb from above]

Board: 4 copper layers, 92.3 x 100.0 mm, 20 parts (0 on the bottom side), 35 nets.

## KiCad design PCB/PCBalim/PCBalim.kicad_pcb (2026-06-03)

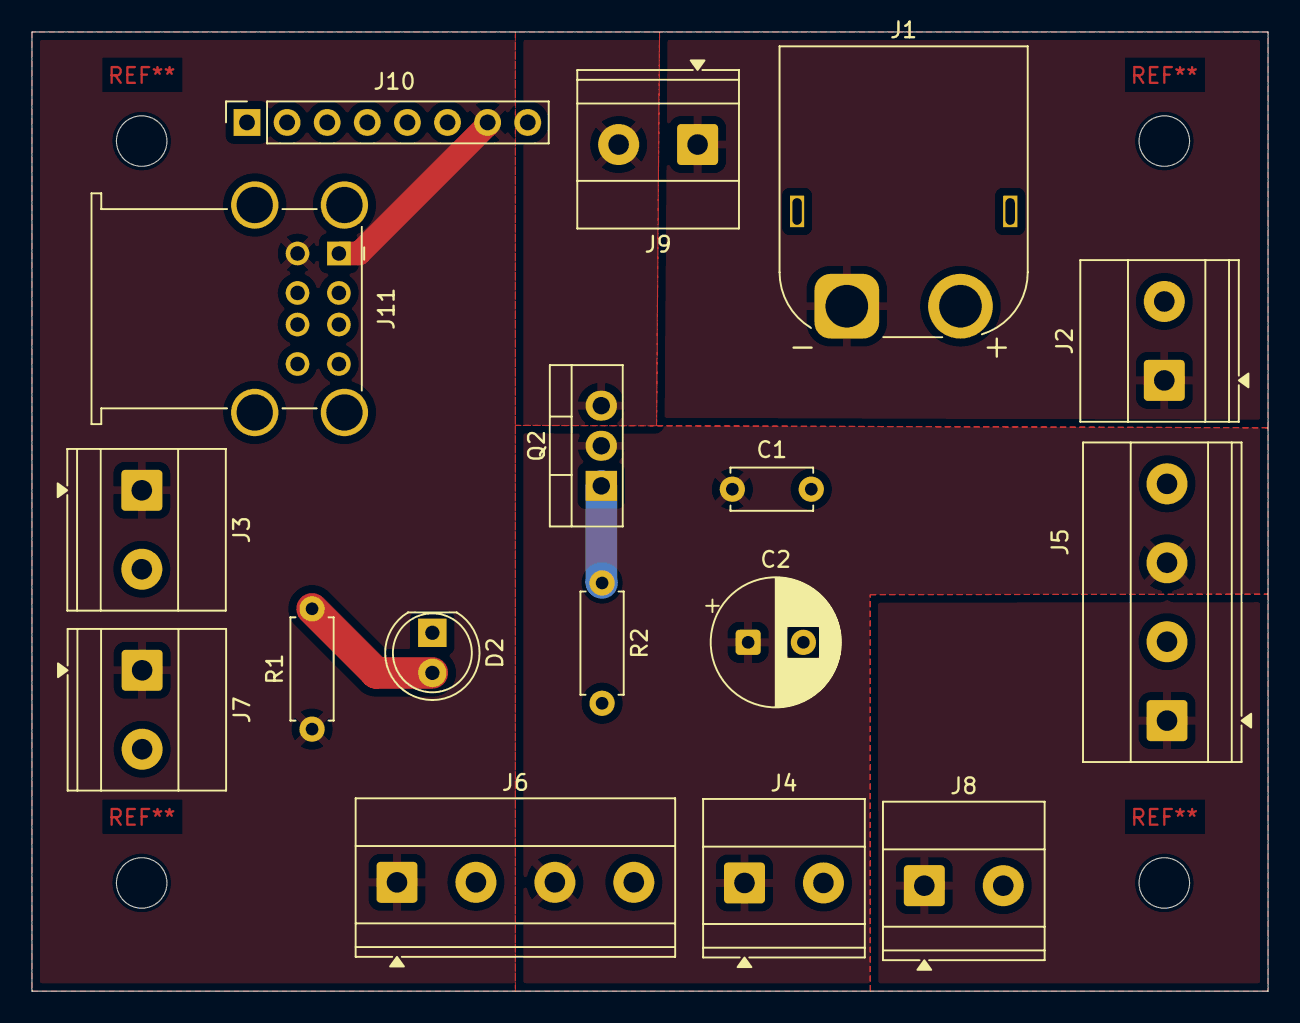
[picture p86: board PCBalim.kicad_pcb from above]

Board: 2 copper layers, 78.3 x 60.8 mm, 17 parts (0 on the bottom side), 8 nets.

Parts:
C1: Ceramico 100nF (50V); C_Disc_D5.0mm_W2.5mm_P5.00mm
C2: Elettronico 100µF (35V); CP_Radial_D8.0mm_P3.50mm
D2: LED; LED_D5.0mm
J1: XT60PW-M; AMASS_XT60PW-M_1x02_P7.20mm_Horizontal
J2: AlimTest; TerminalBlock_Phoenix_MKDS-1,5-2_1x02_P5.00mm_Horizontal
J3: 5V (OFE); TerminalBlock_Phoenix_MKDS-1,5-2_1x02_P5.00mm_Horizontal
J4: 12V (OFE); TerminalBlock_Phoenix_MKDS-1,5-2_1x02_P5.00mm_Horizontal
J5: 12Vout(for6V); TerminalBlock_Phoenix_MKDS-1,5-4_1x04_P5.00mm_Horizontal
J6: 12Vout(5Vin); TerminalBlock_Phoenix_MKDS-1,5-4_1x04_P5.00mm_Horizontal
J7: 5V (OFE)2; TerminalBlock_Phoenix_MKDS-1,5-2_1x02_P5.00mm_Horizontal
J8: 6V (OFE)2; TerminalBlock_Phoenix_MKDS-1,5-2_1x02_P5.00mm_Horizontal
J9: FUSE HOLDER (IN-OUT); TerminalBlock_Phoenix_MKDS-1,5-2_1x02_P5.00mm_Horizontal
J10: ConnBreakOutUSBC; PinSocket_1x08_P2.54mm_Vertical
J11: USB_A (ToESPDRONE/DISPLAY); USB_A_Wuerth_61400826021_Horizontal_Stacked
Q2: IRF4905; TO-220-3_Vertical
R1: 560 Ohm; R_Axial_DIN0207_L6.3mm_D2.5mm_P7.62mm_Horizontal
R2: 10k Ohm; R_Axial_DIN0207_L6.3mm_D2.5mm_P7.62mm_Horizontal

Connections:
+5V: J3.1, J6.1, J7.1, J10.7, J11.1 (VBUS1), J11.5 (VBUS2), R1.1
+6V: J5.1, J8.1
+12V: C1.1, C2.1, J4.1, J5.3, J6.3, Q2.2 (D)
/12Out: J1.1, J2.1, J9.1
/12Vin: J9.2, Q2.3 (S)
GND: C1.2, C2.2, D2.1 (K), J1.2, J2.2, J3.2, J4.2, J5.2, J5.4, J6.2, J6.4, J7.2, J8.2, J10.8, J11.4 (GND1), J11.8 (GND2), J11.9 (Shield), R2.2
unnamed: D2.2 (A), R1.2
unnamed: Q2.1 (G), R2.1

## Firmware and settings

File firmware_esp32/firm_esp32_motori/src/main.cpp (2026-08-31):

/*
 * ================================================================
 *  ESP32 MOTORI — FIRMWARE SOLO I2C (WiFi/MQTT rimossi)
 *  Latenza comando→motore: < 2ms (tipico) / < 5ms (peggiore)
 *
 *  Il Raspberry Pi è l'UNICO punto di comunicazione con l'esterno.
 *  Questo ESP32 parla SOLO via I2C slave (0x08) col Pi — nessun WiFi,
 *  nessun MQTT, nessuna gestione credenziali/broker. Tutto il traffico
 *  verso controller esterni/dashboard passa dal Pi, che poi scrive
 *  qui via I2C con lo stesso protocollo di sempre (opcode invariati).
 *
 *  ARCHITETTURA (invariata rispetto a prima, solo networking rimosso):
 *
 *  1. DUAL-CORE FreeRTOS
 *     - Core 0: libero (nessun task di rete più necessario)
 *     - Core 1: Motori + Encoder + I2C + Seriale (real-time)
 *
 *  2. CODA COMANDI (xQueueSend/Receive)
 *     - I2C ISR → coda → task motori: latenza < 1ms
 *     - Seriale → coda → task motori: latenza < 2ms
 *
 *  3. SICUREZZA ULTRASUONI (invariata)
 *     - Il Raspberry invia periodicamente i dati sensori via I2C
 *       con comando 0xE0 seguito da 26 byte (buffer ESP32 sensori)
 *     - Se un sensore scende sotto la soglia DIST_SOGLIA_*, i movimenti
 *       nella direzione corrispondente vengono bloccati
 *
 * ────────────────────────────────────────────────────────────────
 *  LATENZE ATTESE (misurate su ESP32 240MHz):
 *  I2C     → motore: < 1ms
 *  Seriale → motore: < 2ms
 * ════════════════════════════════════════════════════════════════
 */

#include <Arduino.h>
#include <Wire.h>
#include "freertos/FreeRTOS.h"
#include "freertos/task.h"
#include "freertos/queue.h"

// ── I2C slave ────────────────────────────────────────────────────
#define I2C_SLAVE_ADDR  0x08
#define SDA_PIN         21
#define SCL_PIN         22

// canali
#define FL_CH 0
#define FR_CH 1
#define RL_CH 2
#define RR_CH 3

// ════════════════════════════════════════════════════════════════
//  SOGLIE SICUREZZA ULTRASUONI — MODIFICA QUI
//
//  Distanza minima (cm) sotto la quale il movimento nella direzione
//  corrispondente viene BLOCCATO, qualunque sia il comando ricevuto.
//
//  Metti 0 per disabilitare il blocco su un sensore specifico.
//  Metti 9999 per bloccare sempre quella direzione (test).
//
//  I valori 9999 nel buffer sensori indicano "sensore fuori portata"
//  (>300 cm o timeout): in quel caso il blocco NON si attiva.
// ════════════════════════════════════════════════════════════════
#define DIST_SOGLIA_FRONTE    0   // cm — blocca avanti
#define DIST_SOGLIA_RETRO     0   // cm — blocca indietro
#define DIST_SOGLIA_SINISTRA  0   // cm — blocca laterale sinistra
#define DIST_SOGLIA_DESTRA    0   // cm — blocca laterale destra
#define DIST_SOGLIA_CLIFF_F   0   // cm — blocca avanti (bordo)
#define DIST_SOGLIA_CLIFF_R   0   // cm — blocca indietro (bordo)

// Timeout sensori: se non riceviamo dati dal Pi entro questo tempo
// (ms), consideriamo i sensori "sconosciuti" e blocchiamo tutto
// per sicurezza. Metti 0 per disabilitare il timeout.
#define SENSOR_DATA_TIMEOUT_MS  0

// ── PIN MOTORE FL ─────────────────────────────────────────────────
#define FL_PWM    25
#define FL_IN1    26
#define FL_IN2    27
#define FL_ENC_A  13
#define FL_ENC_B  15

// ── PIN MOTORE FR ─────────────────────────────────────────────────
#define FR_PWM    33
#define FR_IN1    12
#define FR_IN2     2
#define FR_ENC_A  34
#define FR_ENC_B  35

// ── PIN MOTORE RL ─────────────────────────────────────────────────
#define RL_PWM    16
#define RL_IN1    17
#define RL_IN2     5
#define RL_ENC_A  36
#define RL_ENC_B  39

// ── PIN MOTORE RR ─────────────────────────────────────────────────
#define RR_PWM    23
#define RR_IN1    19
#define RR_IN2    18
#define RR_ENC_A   4
#define RR_ENC_B  32

// ── STBY condiviso ────────────────────────────────────────────────
#define STBY      14

// ── PWM ──────────────────────────────────────────────────────────
#define PWM_FREQ  5000
#define PWM_RES   8

// ── CODA COMANDI ─────────────────────────────────────────────────
#define CMD_QUEUE_SIZE 32

// ════════════════════════════════════════════════════════════════
//  TIPI
// ════════════════════════════════════════════════════════════════

enum DirezioneCmd {
  DIR_AVANTI, DIR_INDIETRO, DIR_SX, DIR_DX,
  DIR_DIAG_AVT_DX, DIR_DIAG_AVT_SX, DIR_DIAG_IND_DX, DIR_DIAG_IND_SX,
  DIR_RUOTA, DIR_NESSUNA
};

enum CmdType : uint8_t {
  CMD_STOP = 0,
  CMD_AVANTI,
  CMD_INDIETRO,
  CMD_LAT_SX,
  CMD_LAT_DX,
  CMD_DIAG_AVT_DX,
  CMD_DIAG_AVT_SX,
  CMD_DIAG_IND_DX,
  CMD_DIAG_IND_SX,
  CMD_RUOTA_DX,
  CMD_RUOTA_SX,
  CMD_SET_MOTORI,
  CMD_MECANUM,
  CMD_GIRA_ANGOLO,
  CMD_SET_VEL,
  CMD_RESET_ENC,
  CMD_MOTOR_SINGLE,
  CMD_SENSOR_DATA,      // dati sensori dal Pi via I2C 0xE0
};

struct MotorCmd {
  CmdType type;
  int16_t val[4];
  float   valF;
  char    strBuf[192];
};

// ── STATO CONDIVISO ──────────────────────────────────────────────
static portMUX_TYPE encMux    = portMUX_INITIALIZER_UNLOCKED;
static portMUX_TYPE txBufMux  = portMUX_INITIALIZER_UNLOCKED;
static portMUX_TYPE sensorMux = portMUX_INITIALIZER_UNLOCKED;

volatile long encoderFL = 0, encoderFR = 0;
volatile long encoderRL = 0, encoderRR = 0;
volatile int  lastEncFL = 0, lastEncFR = 0;
volatile int  lastEncRL = 0, lastEncRR = 0;

int     velocita    = 150;
uint8_t statoMotori = 0;
int     velFL = 0, velFR = 0, velRL = 0, velRR = 0;

const long TICKS_PER_360 = 1200;

// ── BUFFER I2C TX ─────────────────────────────────────────────────
#define TX_BUF_SIZE 28
volatile uint8_t txBuf[TX_BUF_SIZE];

// ── DATI SENSORI RICEVUTI DAL RASPBERRY (via I2C, non WiFi) ──────
#define SENSOR_BUF_SIZE 26
volatile uint8_t  sensorBuf[SENSOR_BUF_SIZE];
volatile uint32_t lastSensorUpdateMs = 0;
volatile bool     sensorDataValid    = false;

// ── HANDLE RTOS ──────────────────────────────────────────────────
QueueHandle_t cmdQueue;
TaskHandle_t  motorTaskHandle  = nullptr;
TaskHandle_t  serialTaskHandle = nullptr;
TaskHandle_t  printTaskHandle  = nullptr;

// ════════════════════════════════════════════════════════════════
//  PROTOTIPI
// ════════════════════════════════════════════════════════════════
void motorControl(int pwmPin, int in1, int in2, int speed);
void setMotori(int fl, int fr, int rl, int rr);
void fermati();
void avanti(int v);
void indietro(int v);
void lateraleSx(int v);
void lateraleDx(int v);
void diagAvantiDx(int v);
void diagAvantiSx(int v);
void diagIndietroDx(int v);
void diagIndietroSx(int v);
void ruotaDx(int v);
void ruotaSx(int v);
void mecanumDrive(int vx, int vy, int vr);
void giraDiAngolo(float gradi, int vel);
void buildTxBuf();
void eseguiCmd(const MotorCmd& cmd);
void sendCmd(CmdType type, int v0=0, int v1=0, int v2=0, int v3=0, float f=0);
void printHelp();
void printEncoder();
void printStato();
uint16_t getSensorDist(int idx);
bool distanzaBloccante(uint16_t dist, uint16_t soglia);
bool isDirezioneBlocata(DirezioneCmd dir);

// ════════════════════════════════════════════════════════════════
//  SICUREZZA ULTRASUONI — lettura buffer e logica blocco
// ════════════════════════════════════════════════════════════════

inline uint16_t getSensorDist(int idx) {
  int o = idx * 2;
  portENTER_CRITICAL(&sensorMux);
  uint16_t v = sensorBuf[o] | ((uint16_t)sensorBuf[o+1] << 8);
  portEXIT_CRITICAL(&sensorMux);
  return v;
}

inline bool distanzaBloccante(uint16_t dist, uint16_t soglia) {
  if (soglia == 0)    return false;
  if (dist == 9999)   return false;
  return dist < soglia;
}

bool isDirezioneBlocata(DirezioneCmd dir) {
  if (SENSOR_DATA_TIMEOUT_MS > 0) {
    uint32_t now = millis();
    portENTER_CRITICAL(&sensorMux);
    bool     valido  = sensorDataValid;
    uint32_t lastUpd = lastSensorUpdateMs;
    portEXIT_CRITICAL(&sensorMux);
    if (!valido || (now - lastUpd) > SENSOR_DATA_TIMEOUT_MS) {
      return true;
    }
  }

  uint16_t fronte  = getSensorDist(0);
  uint16_t retro   = getSensorDist(1);
  uint16_t sx      = getSensorDist(2);
  uint16_t dx      = getSensorDist(3);
  uint16_t cliff_f = getSensorDist(4);
  uint16_t cliff_r = getSensorDist(5);

  bool blk_fronte = distanzaBloccante(fronte,  DIST_SOGLIA_FRONTE)
                  || distanzaBloccante(cliff_f, DIST_SOGLIA_CLIFF_F);
  bool blk_retro  = distanzaBloccante(retro,   DIST_SOGLIA_RETRO)
                  || distanzaBloccante(cliff_r, DIST_SOGLIA_CLIFF_R);
  bool blk_sx     = distanzaBloccante(sx,      DIST_SOGLIA_SINISTRA);
  bool blk_dx     = distanzaBloccante(dx,      DIST_SOGLIA_DESTRA);

  switch (dir) {
    case DIR_AVANTI:       return blk_fronte;
    case DIR_INDIETRO:     return blk_retro;
    case DIR_SX:           return blk_sx;
    case DIR_DX:           return blk_dx;
    case DIR_DIAG_AVT_DX:  return blk_fronte || blk_dx;
    case DIR_DIAG_AVT_SX:  return blk_fronte || blk_sx;
    case DIR_DIAG_IND_DX:  return blk_retro  || blk_dx;
    case DIR_DIAG_IND_SX:  return blk_retro  || blk_sx;
    case DIR_RUOTA:        return false;
    case DIR_NESSUNA:      return false;
    default:               return false;
  }
}

// ════════════════════════════════════════════════════════════════
//  HELPER — invio comando alla coda
// ════════════════════════════════════════════════════════════════

inline void sendCmd(CmdType type, int v0, int v1, int v2, int v3, float f) {
  MotorCmd cmd = {};
  cmd.type   = type;
  cmd.val[0] = (int16_t)v0;
  cmd.val[1] = (int16_t)v1;
  cmd.val[2] = (int16_t)v2;
  cmd.val[3] = (int16_t)v3;
  cmd.valF   = f;
  xQueueSend(cmdQueue, &cmd, 0);
}

// ════════════════════════════════════════════════════════════════
//  ENCODER ISR
// ════════════════════════════════════════════════════════════════

void IRAM_ATTR updateEncoderFL() {
  int enc = (digitalRead(FL_ENC_A) << 1) | digitalRead(FL_ENC_B);
  int sum = (lastEncFL << 2) | enc;
  portENTER_CRITICAL_ISR(&encMux);
  if (sum==0b1101||sum==0b0100||sum==0b0010||sum==0b1011) encoderFL++;
  if (sum==0b1110||sum==0b0111||sum==0b0001||sum==0b1000) encoderFL--;
  portEXIT_CRITICAL_ISR(&encMux);
  lastEncFL = enc;
}
void IRAM_ATTR updateEncoderFR() {
  int enc = (digitalRead(FR_ENC_A) << 1) | digitalRead(FR_ENC_B);
  int sum = (lastEncFR << 2) | enc;
  portENTER_CRITICAL_ISR(&encMux);
  if (sum==0b1101||sum==0b0100||sum==0b0010||sum==0b1011) encoderFR++;
  if (sum==0b1110||sum==0b0111||sum==0b0001||sum==0b1000) encoderFR--;
  portEXIT_CRITICAL_ISR(&encMux);
  lastEncFR = enc;
}
void IRAM_ATTR updateEncoderRL() {
  int enc = (digitalRead(RL_ENC_A) << 1) | digitalRead(RL_ENC_B);
  int sum = (lastEncRL << 2) | enc;
  portENTER_CRITICAL_ISR(&encMux);
  if (sum==0b1101||sum==0b0100||sum==0b0010||sum==0b1011) encoderRL++;
  if (sum==0b1110||sum==0b0111||sum==0b0001||sum==0b1000) encoderRL--;
  portEXIT_CRITICAL_ISR(&encMux);
  lastEncRL = enc;
}
void IRAM_ATTR updateEncoderRR() {
  int enc = (digitalRead(RR_ENC_A) << 1) | digitalRead(RR_ENC_B);
  int sum = (lastEncRR << 2) | enc;
  portENTER_CRITICAL_ISR(&encMux);
  if (sum==0b1101||sum==0b0100||sum==0b0010||sum==0b1011) encoderRR++;
  if (sum==0b1110||sum==0b0111||sum==0b0001||sum==0b1000) encoderRR--;
  portEXIT_CRITICAL_ISR(&encMux);
  lastEncRR = enc;
}

// ════════════════════════════════════════════════════════════════
//  MOTORI — basso livello
// ════════════════════════════════════════════════════════════════

void IRAM_ATTR motorControl(int channel, int in1, int in2, int speed) {
  speed = constrain(speed, -255, 255);
  if (speed > 0)      { digitalWrite(in1, HIGH); digitalWrite(in2, LOW);  ledcWrite(channel,  speed); }
  else if (speed < 0) { digitalWrite(in1, LOW);  digitalWrite(in2, HIGH); ledcWrite(channel, -speed); }
  else                { digitalWrite(in1, LOW);  digitalWrite(in2, LOW);  ledcWrite(channel,  0);     }
}

void IRAM_ATTR setMotori(int fl, int fr, int rl, int rr) {
  velFL = fl; velFR = fr; velRL = rl; velRR = rr;
  motorControl(FL_CH, FL_IN1, FL_IN2, fl);
  motorControl(FR_CH, FR_IN1, FR_IN2, fr);
  motorControl(RL_CH, RL_IN1, RL_IN2, rl);
  motorControl(RR_CH, RR_IN1, RR_IN2, rr);
}

void setMotoriCorrected(int fl, int fr, int rl, int rr) {
  setMotori(-fl, fr, -rl, rr);
}

void fermati() { setMotori(0,0,0,0); statoMotori=0; buildTxBuf(); }

void avanti(int v)         { setMotoriCorrected( v, v, v, v);   statoMotori=1; buildTxBuf(); }
void indietro(int v)       { setMotoriCorrected(-v,-v,-v,-v);   statoMotori=1; buildTxBuf(); }
void lateraleDx(int v)  { setMotoriCorrected( v,-v,-v, v);  statoMotori=1; buildTxBuf(); }
void lateraleSx(int v)  { setMotoriCorrected(-v, v, v,-v);  statoMotori=1; buildTxBuf(); }
void diagAvantiDx(int v)   { setMotoriCorrected( v, 0, 0, v);   statoMotori=1; buildTxBuf(); }
void diagAvantiSx(int v)   { setMotoriCorrected( 0, v, v, 0);   statoMotori=1; buildTxBuf(); }
void diagIndietroDx(int v) { setMotoriCorrected( 0,-v,-v, 0);   statoMotori=1; buildTxBuf(); }
void diagIndietroSx(int v) { setMotoriCorrected(-v, 0, 0,-v);   statoMotori=1; buildTxBuf(); }
void ruotaDx(int v)        { setMotoriCorrected( v,-v, v,-v);   statoMotori=2; buildTxBuf(); }
void ruotaSx(int v)        { setMotoriCorrected(-v, v,-v, v);   statoMotori=2; buildTxBuf(); }

void mecanumDrive(int vx, int vy, int vr) {
  int fl = vy+vx+vr, fr = vy-vx-vr;
  int rl = vy-vx+vr, rr = vy+vx-vr;
  int mx = max({abs(fl),abs(fr),abs(rl),abs(rr)});
  if (mx > 255) { fl=fl*255/mx; fr=fr*255/mx; rl=rl*255/mx; rr=rr*255/mx; }
  setMotoriCorrected(fl,fr,rl,rr);
  statoMotori = 1;
  buildTxBuf();
}

void giraDiAngolo(float gradi, int vel) {
  if (gradi == 0) return;
  statoMotori = 2;
  long tickTarget = (long)((fabsf(gradi) / 360.0f) * TICKS_PER_360);
  portENTER_CRITICAL(&encMux);
  encoderFL = 0; encoderFR = 0;
  portEXIT_CRITICAL(&encMux);
  if (gradi > 0) ruotaDx(vel); else ruotaSx(vel);
  while (true) {
    long fl, fr;
    portENTER_CRITICAL(&encMux);
    fl = encoderFL; fr = encoderFR;
    portEXIT_CRITICAL(&encMux);
    long percorsi = (abs(fl) + abs(fr)) / 2;
    if (percorsi >= tickTarget) break;
    float pct = (float)percorsi / tickTarget;
    if (pct > 0.85f) {
      int vr = max(80, (int)(vel * (1.0f - pct) * 6.67f));
      if (gradi > 0) ruotaDx(vr); else ruotaSx(vr);
    }
    buildTxBuf();
    vTaskDelay(pdMS_TO_TICKS(5));
  }
  fermati();
  vTaskDelay(pdMS_TO_TICKS(150));
}

// ════════════════════════════════════════════════════════════════
//  BUFFER TX
// ════════════════════════════════════════════════════════════════

void buildTxBuf() {
  long fl, fr, rl, rr;
  portENTER_CRITICAL(&encMux);
  fl = encoderFL; fr = encoderFR; rl = encoderRL; rr = encoderRR;
  portEXIT_CRITICAL(&encMux);
  portENTER_CRITICAL(&txBufMux);
  auto writeI32 = [](volatile uint8_t* buf, int offset, long val) {
    buf[offset]   = (uint8_t)(val        & 0xFF);
    buf[offset+1] = (uint8_t)((val >> 8) & 0xFF);
    buf[offset+2] = (uint8_t)((val >>16) & 0xFF);
    buf[offset+3] = (uint8_t)((val >>24) & 0xFF);
  };
  writeI32(txBuf,  0, fl);
  writeI32(txBuf,  4, fr);
  writeI32(txBuf,  8, rl);
  writeI32(txBuf, 12, rr);
  txBuf[16] = (uint8_t)velocita;
  txBuf[17] = statoMotori;
  txBuf[18] = (uint8_t)(constrain(velFL, -127, 127) + 128);
  txBuf[19] = (uint8_t)(constrain(velFR, -127, 127) + 128);
  txBuf[20] = (uint8_t)(constrain(velRL, -127, 127) + 128);
  txBuf[21] = (uint8_t)(constrain(velRR, -127, 127) + 128);
  txBuf[22] = txBuf[23] = txBuf[24] = txBuf[25] = txBuf[26] = txBuf[27] = 0;
  portEXIT_CRITICAL(&txBufMux);
}

// ════════════════════════════════════════════════════════════════
//  ESEGUI COMANDO DAL QUEUE
// ════════════════════════════════════════════════════════════════

void eseguiCmd(const MotorCmd& c) {
  switch (c.type) {
    case CMD_STOP: fermati(); break;

    case CMD_AVANTI:
      if (isDirezioneBlocata(DIR_AVANTI))
        { fermati(); Serial.println("[SAFETY] AVANTI bloccato (ostacolo/cliff frontale)"); }
      else avanti(velocita);
      break;

    case CMD_INDIETRO:
      if (isDirezioneBlocata(DIR_INDIETRO))
        { fermati(); Serial.println("[SAFETY] INDIETRO bloccato (ostacolo/cliff posteriore)"); }
      else indietro(velocita);
      break;

    case CMD_LAT_SX:
      if (isDirezioneBlocata(DIR_SX))
        { fermati(); Serial.println("[SAFETY] LAT_SX bloccato (ostacolo sinistra)"); }
      else lateraleSx(velocita);
      break;

    case CMD_LAT_DX:
      if (isDirezioneBlocata(DIR_DX))
        { fermati(); Serial.println("[SAFETY] LAT_DX bloccato (ostacolo destra)"); }
      else lateraleDx(velocita);
      break;

    case CMD_DIAG_AVT_DX:
      if (isDirezioneBlocata(DIR_DIAG_AVT_DX))
        { fermati(); Serial.println("[SAFETY] DIAG_AVT_DX bloccato"); }
      else diagAvantiDx(velocita);
      break;

    case CMD_DIAG_AVT_SX:
      if (isDirezioneBlocata(DIR_DIAG_AVT_SX))
        { fermati(); Serial.println("[SAFETY] DIAG_AVT_SX bloccato"); }
      else diagAvantiSx(velocita);
      break;

    case CMD_DIAG_IND_DX:
      if (isDirezioneBlocata(DIR_DIAG_IND_DX))
        { fermati(); Serial.println("[SAFETY] DIAG_IND_DX bloccato"); }
      else diagIndietroDx(velocita);
      break;

    case CMD_DIAG_IND_SX:
      if (isDirezioneBlocata(DIR_DIAG_IND_SX))
        { fermati(); Serial.println("[SAFETY] DIAG_IND_SX bloccato"); }
      else diagIndietroSx(velocita);
      break;

    case CMD_RUOTA_DX: ruotaDx(velocita); break;
    case CMD_RUOTA_SX: ruotaSx(velocita); break;

    case CMD_SET_VEL:
      velocita = constrain((int)c.val[0], 0, 255);
      break;

    case CMD_RESET_ENC:
      portENTER_CRITICAL(&encMux);
      encoderFL = encoderFR = encoderRL = encoderRR = 0;
      portEXIT_CRITICAL(&encMux);
      break;

    case CMD_SET_MOTORI: {
      int fl = c.val[0], fr = c.val[1], rl = c.val[2], rr = c.val[3];
      int vy = (fl + fr + rl + rr) / 4;
      int vx = (-fl + fr + rl - rr) / 4;
      bool blocked = false;
      if (vy > 0 && isDirezioneBlocata(DIR_AVANTI))   { blocked = true; Serial.println("[SAFETY] SET_MOTORI bloccato (fronte)"); }
      if (vy < 0 && isDirezioneBlocata(DIR_INDIETRO)) { blocked = true; Serial.println("[SAFETY] SET_MOTORI bloccato (retro)"); }
      if (vx > 0 && isDirezioneBlocata(DIR_DX))       { blocked = true; Serial.println("[SAFETY] SET_MOTORI bloccato (destra)"); }
      if (vx < 0 && isDirezioneBlocata(DIR_SX))       { blocked = true; Serial.println("[SAFETY] SET_MOTORI bloccato (sinistra)"); }
      if (!blocked) {
        setMotori(fl, fr, rl, rr);
        statoMotori = (fl==0&&fr==0&&rl==0&&rr==0) ? 0 : 1;
        buildTxBuf();
      } else {
        fermati();
      }
      break;
    }

    case CMD_MECANUM: {
      int vx = c.val[0], vy = c.val[1], vr = c.val[2];
      bool blocked = false;
      if (vy > 0 && isDirezioneBlocata(DIR_AVANTI))   { blocked = true; Serial.println("[SAFETY] MECANUM bloccato (fronte)"); }
      if (vy < 0 && isDirezioneBlocata(DIR_INDIETRO)) { blocked = true; Serial.println("[SAFETY] MECANUM bloccato (retro)"); }
      if (vx > 0 && isDirezioneBlocata(DIR_DX))       { blocked = true; Serial.println("[SAFETY] MECANUM bloccato (destra)"); }
      if (vx < 0 && isDirezioneBlocata(DIR_SX))       { blocked = true; Serial.println("[SAFETY] MECANUM bloccato (sinistra)"); }
      if (!blocked) mecanumDrive(vx, vy, vr);
      else fermati();
      break;
    }

    case CMD_GIRA_ANGOLO:
      giraDiAngolo(c.valF, (int)c.val[0]);
      break;

    case CMD_MOTOR_SINGLE: {
      int motore = c.val[0];
      int speed  = c.val[1];
      switch (motore) {
        case 0: motorControl(FL_CH,FL_IN1,FL_IN2,speed); velFL=speed; break;
        case 1: motorControl(FR_CH,FR_IN1,FR_IN2,speed); velFR=speed; break;
        case 2: motorControl(RL_CH,RL_IN1,RL_IN2,speed); velRL=speed; break;
        case 3: motorControl(RR_CH,RR_IN1,RR_IN2,speed); velRR=speed; break;
      }
      statoMotori = (velFL==0&&velFR==0&&velRL==0&&velRR==0) ? 0 : 1;
      buildTxBuf();
      break;
    }

    case CMD_SENSOR_DATA: {
      portENTER_CRITICAL(&sensorMux);
      memcpy((void*)sensorBuf, c.strBuf, SENSOR_BUF_SIZE);
      lastSensorUpdateMs = millis();
      sensorDataValid    = true;
      portEXIT_CRITICAL(&sensorMux);
      break;
    }
  }
}

// ════════════════════════════════════════════════════════════════
//  I2C SLAVE CALLBACKS — UNICO canale di comunicazione col Pi
// ════════════════════════════════════════════════════════════════

void onRequest() {
  portENTER_CRITICAL_ISR(&txBufMux);
  Wire.write((uint8_t*)txBuf, TX_BUF_SIZE);
  portEXIT_CRITICAL_ISR(&txBufMux);
}
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
void loop() {
  vTaskDelay(pdMS_TO_TICKS(1000));
}

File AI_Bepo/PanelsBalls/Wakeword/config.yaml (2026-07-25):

# config.yaml - Configurazione centralizzata pipeline wake word

wake_word:
  name: "nova"          # era "aria"
  phonemes: "noʊvə"
  similar_words: ["nova", "bova", "rova", "nuova", "lova"]  # per dataset negativo hard

audio:
  sample_rate: 16000          # Hz - standard openWakeWord
  chunk_size: 1280            # 80ms @ 16kHz - bilanciamento latenza/CPU
  channels: 1                 # mono
  dtype: "int16"
  bit_depth: 16

dataset:
  positive:
    target_samples: 20000     # campioni TTS da generare
    voices_per_engine: 10     # voci TTS diverse
    speed_range: [0.85, 1.15] # variazione velocità
    pitch_range: [-3, 3]      # semitoni
    phrases:
      - "{wake_word}"
      - "hey {wake_word}"
      - "ok {wake_word}"
      - "{wake_word} ascoltami"
      - "ciao {wake_word}"
  negative:
    target_hours: 500
    sources:
      - "common_voice"        # Mozilla Common Voice
      - "librispeech"         # LibriSpeech ASR corpus
      - "musan"               # Music/Speech/Noise dataset
      - "freesound"           # Rumori domestici
    hard_negatives:           # Parole simili - critiche!
      - "area"
      - "maria"
      - "varia"

augmentation:
  noise:
    snr_range_db: [5, 30]     # SNR basso = molto rumore
    types: ["white", "pink", "babble", "domestic"]
  reverb:
    room_scale: [0.1, 0.5]    # 0=anechoica, 1=grande stanza
    wet_level: [0.0, 0.3]     # livello riverbero (basso per non degradare)
  distance:
    near_db: 0
    far_db: -18               # simulazione 3-5 metri
  time_stretch: [0.9, 1.1]

training:
  backbone: "google/speecht5_tts"  # feature extractor pre-trained
  model_type: "dnn"                # dnn | rnn - dnn più veloce su CPU
  hidden_units: [128, 64, 32]      # architettura leggera
  dropout: 0.3
  batch_size: 256
  epochs: 100
  learning_rate: 0.001
  early_stopping_patience: 10
  val_split: 0.1
  positive_weight: 5.0             # peso campioni positivi (dataset sbilanciato)

optimization:
  format: "tflite"                 # tflite | onnx
  quantization: "int8"             # int8 | fp16 | dynamic
  target_device: "rpi"
  expected_model_size_kb: 200      # target < 500KB

inference:
  threshold: 0.70                  # soglia base
  smoothing_window: 4              # media mobile su N frame
  refractory_period_s: 2.0         # pausa dopo detection
  vad_enabled: true                # abilita VAD per risparmio CPU
  vad_threshold: 0.5
  debug_mode: false

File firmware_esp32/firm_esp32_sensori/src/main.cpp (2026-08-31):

/*
 * ================================================================
 *  ESP32 SENSORI — FIRMWARE SOLO I2C (WiFi/MQTT rimossi)
 *
 *  Il Raspberry Pi è l'UNICO punto di comunicazione con l'esterno.
 *  Questo ESP32 parla SOLO via I2C slave (0x09) col Pi — nessun WiFi,
 *  nessun MQTT, nessuna gestione credenziali/broker/mDNS. Tutto il
 *  traffico verso controller esterni/dashboard passa dal Pi, che
 *  legge il buffer sensori via I2C e scrive comandi servo via I2C.
 *
 *  FIX rispetto alla versione con WiFi/MQTT:
 *
 *  1. RIMOSSO tutto il networking (WiFi, MQTT, mDNS, NVS credenziali,
 *     ArduinoJson — non più necessario senza parsing JSON via MQTT)
 *
 *  2. AGGIUNTO opcode I2C 0xAD (ch, ang) → enqueueServo() [smooth]
 *     Il bridge Python sul Pi (testI2C.py) manda già questo opcode
 *     per i comandi servo (sia da MQTT robot/sensori/cmd sia da UDP
 *     diretto porta 5566) — prima d'ora l'I2C handler qui riconosceva
 *     solo 0xAA (posizione immediata) e 0xAB (relativo immediato),
 *     quindi 0xAD veniva SEMPRE ignorato silenziosamente: i comandi
 *     servo dal Pi non arrivavano mai a destinazione via I2C.
 *     Ora 0xAD usa la coda smooth (stesso movimento graduale già
 *     usato dai comandi seriali s0..s6).
 *
 *  3. ULTRASUONI — rivisti per correttezza e frequenza:
 *     - Macchina a stati a 3 fasi (ST_IDLE → ST_TRIG_HIGH → ST_WAIT_END)
 *       con lettura ISR atomica (noInterrupts/interrupts): CORRETTA,
 *       nessun bug di race condition trovato.
 *     - Timeout eco: 25ms = ~430cm (formula distanza_cm = durata_us/58
 *       verificata: 25000/58 ≈ 431cm) → margine coerente col taglio
 *       fisico a DIST_MAX_CM=300cm. CORRETTO.
 *     - TRIGGER_INTERVAL_US ridotto da 50ms a 30ms per aumentare la
 *       frequenza di refresh per sensore da ~20Hz a ~33Hz. Lo
 *       sfalsamento iniziale di 9ms tra i 6 sensori (al boot) è
 *       preservato nel tempo perché ogni sensore riprogramma il
 *       proprio prossimo trigger relativamente al proprio timestamp
 *       precedente, non a un clock globale — quindi il rischio di
 *       interferenza acustica tra sensori vicini resta basso.
 *       Se in pratica noti letture erratiche/rumorose con 6 sensori
 *       ravvicinati, alza di nuovo questo valore verso 40-50ms.
 *
 *  4. TUTTO IL RESTO invariato: servo coda smooth, MPU6050, TCRT,
 *     relè, comandi seriali via USB per debug.
 *
 * ────────────────────────────────────────────────────────────────
 *  COMANDI SERIALI (invariati, terminare con Invio):
 *  s0..s6 <gradi>   r0..r6 <delta>   set <s0>..<s6>
 *  raw <ch> <tick>  home  riposo  rele on/off
 *  pos  dist  imu  tcrt  tcrt watch  stato  help
 *
 * ────────────────────────────────────────────────────────────────
 *  COMANDI I2C IN INGRESSO (dal Pi, indirizzo slave 0x09):
 *   0xAA <ch> <ang>        → setServo immediato (0-180, salta la coda)
 *   0xAB <ch> <val+128>    → moveServo relativo immediato
 *   0xAC <val>             → relè (1=on, 0=off)
 *   0xAD <ch> <ang>        → enqueueServo SMOOTH (usato dal Pi bridge)
 *   0xAE                   → home (tutti i servo, smooth)
 *   0xAF                   → riposo (smooth)
 *   0xB0 <ms>              → velocità servo (ms/passo, 1-50)
 *   0xFD / 0xFE            → RIMOSSI (erano credenziali WiFi)
 *
 *  BUFFER I2C IN USCITA (26 byte, richiesta standard I2C read):
 *   [0-11]  distanze ultrasuoni (6 × uint16 LE, cm, 9999=fuori portata)
 *   [12-23] IMU (ax,ay,az,gx,gy,gz) int16 LE ×100
 *   [24]    TCRT mask (bit0=sx bit1=cen bit2=dx, 1=nero)
 *   [25]    relè (0/1)
 *
 * ────────────────────────────────────────────────────────────────
 *  MAPPA SERVO BRACCIO:
 *   CH0 → Base rotazione       CH4 → Polso rotazione
 *   CH1 → Spalla                CH5 → Pinza (home=120°)
 *   CH2 → Gomito                CH6 → Settimo/telecamera (80°-170°, home=125°)
 *   CH3 → Polso verticale
 * ================================================================
 */

#include <Wire.h>
#include <Adafruit_PWMServoDriver.h>
#include <MPU6050_light.h>

// ── I2C ──────────────────────────────────────────────────────────
#define I2C_SLAVE_ADDR 0x09
#define SDA_SLAVE 21
#define SCL_SLAVE 22
#define SDA_MASTER 32
#define SCL_MASTER 33

// ── SERVO (PCA9685 su Wire1) ──────────────────────────────────────
#define SERVO_MIN  102
#define SERVO_MAX  512
#define NUM_SERVO  7

#define SERVO6_MIN_DEG  80
#define SERVO6_MAX_DEG  170

const char* SERVO_NAMES[NUM_SERVO] = {
  "Base      ",
  "Spalla    ",
  "Gomito    ",
  "Polso-V   ",
  "Polso-R   ",
  "Pinza     ",
  "Settimo   "
};

const int SERVO_HOME[NUM_SERVO]   = { 90, 90,  90, 90, 90, 120, 125 };
const int SERVO_RIPOSO[NUM_SERVO] = { 90, 30,  60, 90, 90,  90, 125 };

Adafruit_PWMServoDriver pca = Adafruit_PWMServoDriver(0x40, Wire1);
int servoPos[NUM_SERVO] = { 90, 90, 90, 90, 90, 120, 125 };

// ── CODA SERVO (smooth, sequenziale) ─────────────────────────────
#define SERVO_QUEUE_SIZE 32

struct ServoMove {
  uint8_t ch;
  int     target;
};

ServoMove servoQueue[SERVO_QUEUE_SIZE];
uint8_t   servoQHead  = 0;
uint8_t   servoQTail  = 0;
uint8_t   servoQCount = 0;

int      servoCurrentTarget = -1;
uint32_t lastServoStepMs    = 0;
uint8_t  servoStepMs        = 8;

int  degreesToTick(int deg);

bool enqueueServo(uint8_t ch, int target) {
  if (servoQCount >= SERVO_QUEUE_SIZE) {
    Serial.println(F("[SERVO] Coda piena, mossa scartata!"));
    return false;
  }
  if (ch == 6) target = constrain(target, SERVO6_MIN_DEG, SERVO6_MAX_DEG);
  else         target = constrain(target, 0, 180);
  servoQueue[servoQTail] = { ch, target };
  servoQTail  = (servoQTail + 1) % SERVO_QUEUE_SIZE;
  servoQCount++;
  return true;
}

void updateServoQueue() {
  uint32_t now = millis();
  if ((now - lastServoStepMs) < servoStepMs) return;
  lastServoStepMs = now;

  if (servoCurrentTarget < 0) {
    if (servoQCount == 0) return;
    ServoMove& m = servoQueue[servoQHead];
    servoCurrentTarget = m.target;
    if (servoPos[m.ch] == servoCurrentTarget) {
      servoQHead  = (servoQHead + 1) % SERVO_QUEUE_SIZE;
      servoQCount--;
      servoCurrentTarget = -1;
      return;
    }
  }

  ServoMove& m = servoQueue[servoQHead];

  if      (servoPos[m.ch] < m.target) servoPos[m.ch]++;
  else if (servoPos[m.ch] > m.target) servoPos[m.ch]--;

  pca.setPWM(m.ch, 0, degreesToTick(servoPos[m.ch]));

  if (servoPos[m.ch] == m.target) {
    Serial.printf("[SERVO] S%d %s-> %d gradi OK\n", m.ch, SERVO_NAMES[m.ch], m.target);
    servoQHead  = (servoQHead + 1) % SERVO_QUEUE_SIZE;
    servoQCount--;
    servoCurrentTarget = -1;
  }
}

// ── ULTRASUONI ────────────────────────────────────────────────────
// Stato a 3 fasi. Timeout misurato da quando entriamo in ST_WAIT_END
// (dopo il pulse LOW). echoGot letto atomicamente con noInterrupts().
// echoGot NON viene mai azzerato in ST_IDLE per evitare race condition
// (si azzera solo quando lo leggiamo, in ST_WAIT_END).
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

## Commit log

2026-05-29 Add hardware base
    [pinoutEsp32.xlsx, robot_power_budget_v2.xlsx]
2026-05-29 Add PCB motori
    [pcbMotori-B_Cu.gbr, pcbMotori-B_Mask.gbr, pcbMotori-B_Paste.gbr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]
2026-05-29 Add PCB alim
    [PCBalim-B_Cu.gbr, PCBalim-B_Mask.gbr, PCBalim-B_Paste.gbr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]
2026-06-03 Aggiunta cartella Bamberg
    [BOM(0.2)_ESP32-S2-Drone_V1.2_20200512.xlsx, BOM_200616.xlsx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]
2026-06-03 Aggiunta cartella datasheet
    [coppiaVelocitaMotori.xlsx]
2026-06-03 Rinominata cartella DataShit in Datasheet
    [coppiaVelocitaMotori.xlsx]
2026-06-03 Aggiunta cartella AMAZING BALLS
    [PCA9685.stl]
2026-06-03 Rinominata cartella AMAZING BALLS in AmazingArm
    [PCA9685.stl]
2026-06-29 Updated with 3dModels, RaspCam module, Media module
    [5787617-2.STEP, 5787617-2.stl, 6.ESP-32.SLDPRT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]
2026-07-25 First phase reogranization project
    [5787617-2.STEP, 5787617-2.stl, 6.ESP-32.SLDPRT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]
2026-07-25 Reorganized rasp firmware and AI overview
    [BOM(0.2)_ESP32-S2-Drone_V1.2_20200512.xlsx, BOM_200616.xlsx, ImageToStl.com_Raspberry_Pi_Camera_OV5647_IR-CUT_1752.stl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]
2026-08-27 Added actual raspberry codes
    [BOM(0.2)_ESP32-S2-Drone_V1.2_20200512.xlsx, BOM_200616.xlsx, ImageToStl.com_Raspberry_Pi_Camera_OV5647_IR-CUT_1752.stl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]
2026-08-28 Update with new controller compatibility and graphics with better controls and reworked odometry module
    [GPSmqtt.py, exploration.py, xboxPiDirect.py]
2026-08-31 Updated esp32 firmware with i2c only, removed useles wifi/mqtt leaving only i2c - raspberry connection for faster and more consistent comminication

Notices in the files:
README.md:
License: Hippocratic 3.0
